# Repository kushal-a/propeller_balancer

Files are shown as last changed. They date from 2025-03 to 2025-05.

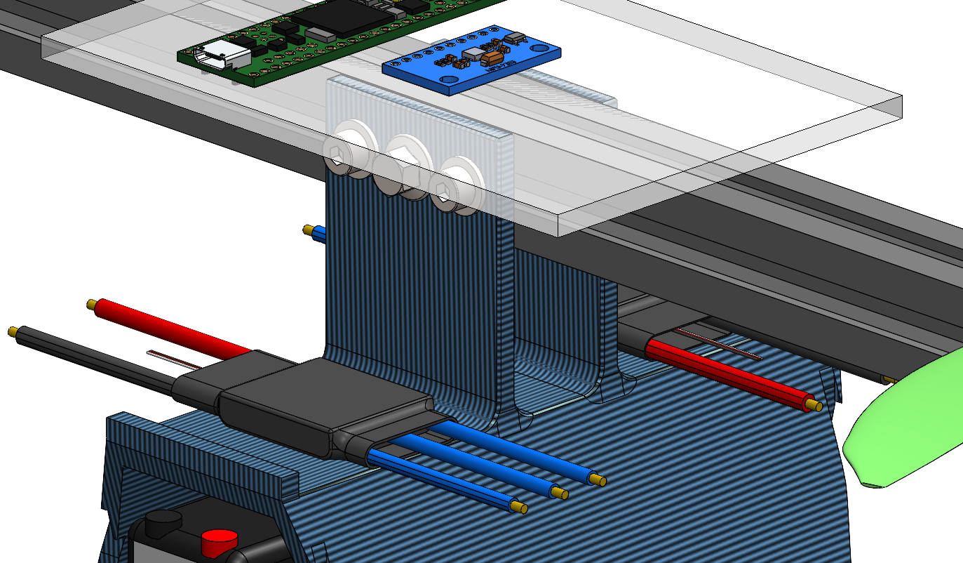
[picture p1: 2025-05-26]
hardware/cad/ESC.png

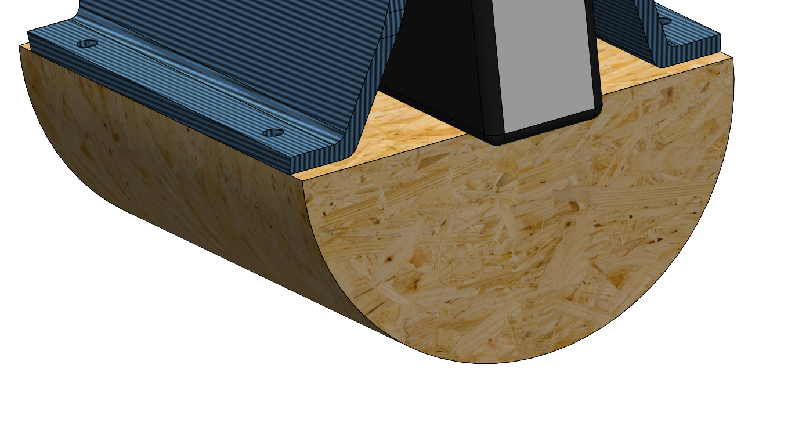
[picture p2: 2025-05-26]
hardware/cad/contact.png

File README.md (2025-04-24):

# propeller_balancer
This repository contains the software required to supervise the `propeller_balancer` developed as a part of my Bachelor's Thesis at Indian Institute of Technology Bombay under the guidance of Prof. Vivek Sangwan. 

# How to use the hardware
The mechanical parts of the project include a semi-circular cylinder on the bottom along with a3D printed part to house the electronics. A 2020T Aluminum profile supports the motors and the end-stops. The acrylic on top of the profile provides space for electronics which are to remain accessible for testing, development and learning.

## Components used
1. Teensy 4.1 microcontroller
2. MPU 6050 IMU sensor for acceleration and gyrometry data
3. 30A BLDC ESC (x2)
4. CC3D BEC (Battery Eliminator Circuit) /Z Power Distribution Board

## Connections
A 10 row port is installed in the hood of the bot. The schematic is shown below.

Internally, the `5V` and `GND` for MUC and IMU are shorted and connected to the Power Distribution board. The `SDA`, `SCL` wires are shorted with jumpers to connect the MUC to the IMU. The `PWMx` pins are connected to the ESC. The `GND` of the ESC's are also connected to the common ground. 

Connect a 10-wire F-F jumper ribbon to the port. First 2 wire connect to `pin1` and `pin2` of the MUC. Next 4 connect to `pins17-14` without twisting. The final 4 connect to the IMU. TODO: Order.

# How to use the package (software)

## Getting started with Teensy

1. Install Arduino IDE
2. Copy and paste the following link in `Arduino IDE`>`File`>`Preferences`>`Additional board manager URLs`
``` html
https://www.pjrc.com/teensy/package_teensy_index.json
```
3. In Arduino IDE go to `Tools`>`Board`>`Board Manager`. Search for Teensy and install the board.
4. Try out your setup with the blink example.
5. Press the button on the Teensy after uploading for it to go into Program mode to receive the compiled code. Once you see Reboot OK, the upload is done.

Ref: https://www.pjrc.com/teensy/tutorial.html

## Setting up IMU
IMU used: MPU 6050 standard IMU sensor

### Power and Communication
Power the IMU with 5V (and GND) from the microcontroller or the power distribution board. For best results, use 5V supply from the power distribution board. 

MPU 6050 uses I2C communication (SDA and SCL) lines. The I2C address of the sensor is 0x68. Connect the SDA and SCL lines of the microcontroller with that of the IMU.

### Software
To communicate with the MPU, we will I2C communication, known as wire communcation in arduino software. Hence, the standard `Wire.h` library will be used. `src/imu` directory has source code for IMU functionality. Import `src/imu/imu.h` for access to IMU functionality. The library provides access to `Theta`, `RateTheta`, `AccX`, `AccY` and `AccZ`. Here, $\theta$ is the nominal angle required for the project. $\theta$ is 0 when the bot balances perfectly.

### Callibration
TODO

## Setting us ESC

### Power and communication
ESC required a 12V input. Connect the two input wires of the ESC with the power supply. ESC provides 3 phase output for motor control; connect the 3 output wires to the motor. It also provides a 5V output (and GND) and takes in a throttle input via jumpers. Ensure to connect the ground of the ESC(s) (and IMU) and microcontroller. The 5V supply of the ESC is unrellibale and hence not used. Throttle is provided as a PWM signal. Speed is proportional to the width of the PWM pulse.

### Software
A BLDC motor with a ESC taking PWM input essentially acts like a servo motor and hence the standard `Servo.h` library is used for producing the PWM. `src/motor` directory has source code for running the motor. Import `src/motor/motor.h` for access to motor functionality. The library provides access to functions to directly produce required PWM signal.

50Hz PWM has is a 20ms period. 
| Duration of high signal per period | Effect in Servo | Effect in BLDC |
| :-----| :----: | :----: |
|1ms|0 degrees|min RPM|
|2ms| 180 degrees|max RPM|

### Callibration 
Every ESC has to caallibrated. The input PWM frequency can vary from 50-60Hz and min max pulse width can vary about 1ms and 2ms respectively. 

For some reason the callibration of both motors simulataneously by code 

## Using the Power Distribution Board
The power distribution board needs a 12V supply. Adjacent to the spots for 12V supply to the ESC. These lines are shorted. On the other end, the 5V terminals will be used to power the microcontroller. The power distribution board has a battery eliminator circuit (BEC) to eliminated the need of a seperate battery for the microcontroller.

# Resources
[1] Teensy KiCAD footprint @ https://github.com/XenGi/teensy.pretty

[2] Teensy KiCAD symbol @ https://github.com/XenGi/teensy_library
# Credits
[1] __Muskan Patel__ and __Kyari Ponkiya__ for initial work on the project.

[2] __Mechatronics Lab__, IIT Bombay for workspace and technological support. __Mr. Tejas__ and __Mr. Vijay__ from Mechatronics Lab.

[3] Members of __INDUS Lab__, IIT Bombay for their support.

[4] __Microfactory__, IIT Bombay with machinary support.

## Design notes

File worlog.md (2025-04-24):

# 24/04
Increased hole size of propeller from 5mm dia to 6mm dia for almost a bit more than half the length from the bottom. This was used for mounting. Cut holes in the center of the motor mounts to give space for the recess part of the shaft coming out of the motor. Assembled the new propellers, base with countersunk holes, motor mounts and endstops

# 23/04

Made countersunk holes in the base and laser cut the supports at Microfactory

# 22/04 

Debugged code for compillation. Received propeller.

# 19/04

Checked for proper propeller size required. Sourced from Amazon. Propeller bought - 6045 

# 17/04

Met with professor for changing the propeller size. Shifting focus to rudimentary implementation at priority

# 15/04

## Testing of motor to get motor constant

### Test 1
#### Aim 
Checking variability of speed of motor (without propeller)
#### Setup
1. Test conducted without propeller. 
2. Code run: motor.ino. 
3. Speed given as % input from Serial monitor.
#### Observations
1. As motor speed input was increasing the motor speed was monotonically increasing. The speed was judged by manually hearing the sound made by the motor. Higher frequency implying faster rotation.
2. Motor only started rotating when motor speed was >=10%

### Test 2

Checking variability of thrust by varying speed of motor-propeller setup
#### Setup
1. Test conducted with propeller. 
2. Code run: motor.ino. 
3. Speed given as % input from Serial monitor.
4. The motor was mounted to a wooden plank and the wooden plank was taped to an iron block of mass ~2.8Kgs. The entire setup is placed on a weighing scale and set to 0 when the motor is not rotating.
#### Observations
1. As motor speed input was increasing the motor-propeller sped up until 40% after which it was abmigious. The speed was judged by manually hearing the sound made by the motor. Higher frequency implying faster rotation.
    1. After this observation, the ESC was recallibrated and test was run again. Same observations were noted.
    2. The propeller was then removed and test 1 was run again. The earlier made observations of test 1 stood again.
2. Motor only started rotating when motor speed was >=10%.
3. Raw data collected from the test is available in `data`>`thrust_test`.

#### Conclusion
1. There is some interference in the motor speed phenomenon on adding the propeller.
2. Current reading should be noted to eliminate current limitng effects.

### Test 3

Checking variability of thrust and current by varying speed of motor-propeller setup
#### Setup
1. Test conducted with propeller. 
2. Code run: motor.ino. 
3. Speed given as % input from Serial monitor.
4. The motor was mounted to a wooden plank and the wooden plank was taped to an iron block of mass ~2.8Kgs. The entire setup is placed on a weighing scale and set to 0 when the motor is not rotating.
#### Observations
1. As motor speed input was increasing the motor-propeller sped up until 40% after which it was abmigious. The speed was judged by manually hearing the sound made by the motor. Higher frequency implying faster rotation.
2. Current reached 1.88A at 40% speed and saturated there after that. The power supply used had a limiting current of 2A.
3. Raw data collected from the test is available in `data`>`thrust_test`.

#### Conclusion
1. Current saturation was causing a drop in observed speed.
2. Higher amperage power supply is to be used.
3. Quadratic treadline fit for 0-40% speed was 

    $$\textit{Thrust (in g)} = 0.036*\textit{Speed}_{\%}^2 + 1.5723*\textit{Speed}_{\%}+0.6373$$ 

    The quadratic and linear part have significant contribution to the calculated value. The constant contributed to <10\% of the calculated value.

### repeating Test 3 with higher amperage power supply

Acrylic broke and the motor flew in air. Luckily the wire came loose and the motor stopped.

DO NOT USE MOTOR WITH speed > 30% !!!!!

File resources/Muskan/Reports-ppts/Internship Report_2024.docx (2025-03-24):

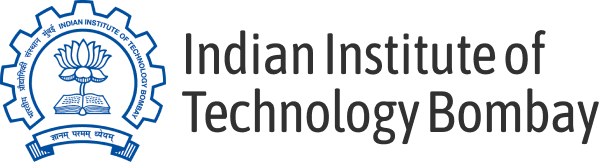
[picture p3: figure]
100+ Top Indian Institute of Technology Bombay Online Courses [2024] | Class Central
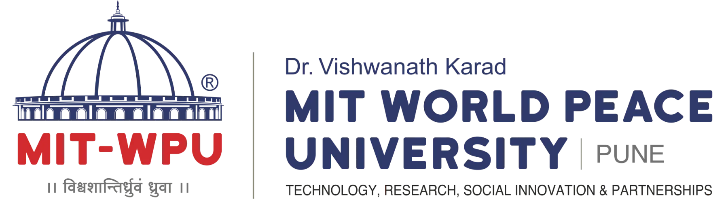
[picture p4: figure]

DESIGN AND CONTROL OF TORSO BALANCING MECHANISM FOR BIPEDAL WALKING ROBOT

An Internship Report Submitted to

DR. VISHWANATH KARAD

MIT WORLD PEACE UNIVERSITY

Submitted by,

Muskan Hiteshkumar Patel (1032200264)

Under the supervision of

Prof. Vivek Sangwan

and

Ass. Prof. Dr. Ashish H. Pawar

School of Mechanical Engineering

MIT World Peace University, Pune

Kothrud, Pune-411038

(Period from 15th January, 2024 to 14th May, 2024)

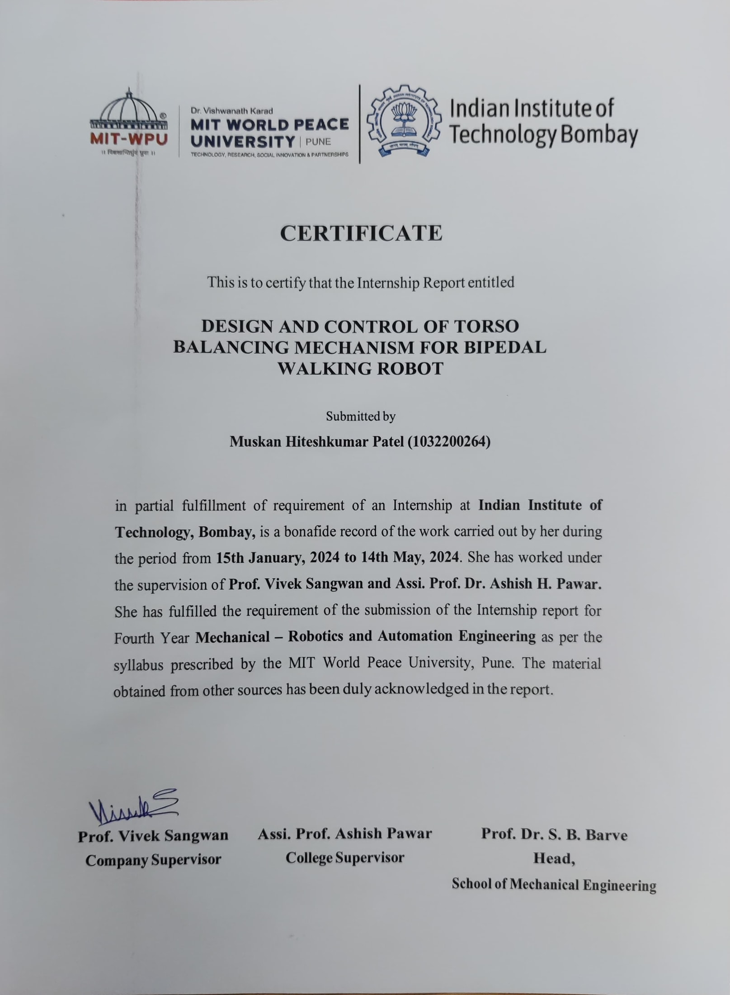
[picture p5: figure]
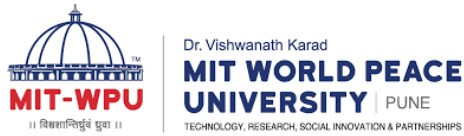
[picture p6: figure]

Vision and Mission

Vision of Faculty of Engineering and Technology

To be a globally recognized leader in Engineering Education having a constructive impact on society.

Mission of Faculty of Engineering and Technology

1. To achieve academic excellence through Continuously Updated Education (CUEd).
2. To create environment of technology research and social innovation by establishing trans-disciplinary centers of excellence.
3. To establish strong partnerships with reputed industry and research organizations.
4. To promote ethical and universal value based professional education.

Vision of School of Mechanical Engineering

To be a center of academic excellence in Mechanical Engineering for sustainable development.

Mission of School of Mechanical Engineering

1. To impart comprehensive knowledge in mechanical engineering and foster skills to enhance economic development of the nation.
2. To facilitate trans-disciplinary research leading to innovative technologies.
3. To collaborate with academia, industry and research organization globally.
4. To nurture students for lifelong learning and ethical professional career.

ACKNOWLEDGEMENT

It gives me great pleasure to work as a research intern on project named “DESIGN AND CONTROL OF TORSO BALANCING MECHANISM FOR BIPEDAL WALKING ROBOT” at IIT Bombay. In presenting this internship project work, a number of hands helped me directly and indirectly. Therefore, it becomes my duty to express my gratitude towards them.

I am grateful to Prof. Dr. Vivek Sangwan for giving me the opportunity to work as an intern at IIT Bombay and giving proper guidance throughout the internship duration. His timely suggestions made it possible to complete this internship for me. All efforts might have gone in vain without his valuable guidance. I would like to express my heart-felt gratitude towards Prof. Dr. Ganesh Kakandikar, in School of Mechanical Engineering, to recommend me for this project under the guidance of Prof. Dr. Vivek Sangwan. I would also like to thank Asst. Prof. Dr. Ashish Pawar for supervising and counselling me on regular basis during the internship.

I will fail in my duty if I won't acknowledge a great sense of gratitude to the head of School of Mechanical Engineering, Prof. Dr. Shivprakash B. Barve and the entire staff members in the School of Mechanical Engineering for their cooperation.

Muskan Hiteshkumar Patel

BTech Mechanical Engg.

PRN No: 1032200264

ABSTRACT

Bipedal walking robots represent a significant advancement in robotics, mimicking human-like locomotion and balancing capabilities. In this study, we focus on the design and control of a torso balancing mechanism for such robots. The proposed mechanism employs a plank structure with two BLDC (Brushless Direct Current) motors mounted on either side, tasked with dynamically stabilizing the robot during locomotion. This research aims to derive the dynamical equations governing the motion of the plank, implement a PID (Proportional-Integral-Derivative) controller to regulate the motor speeds, and integrate feedback from an MPU6050 inertial measurement unit for real-time stability control. The dynamics of the plank are derived using principles of classical mechanics and control theory. The equations of motion consider the inertial properties of the plank, the torques generated by the BLDC motors, and the external disturbances encountered during operation. By modeling the system dynamics, we establish a mathematical framework that governs the interaction between the plank's motion and the control inputs provided by the motors. To achieve stable bipedal locomotion, a PID controller is implemented to regulate the motor speeds in response to deviations from the desired orientation. The PID controller utilizes feedback from the MPU6050 IMU, which provides accurate measurements of the plank's orientation and angular velocities. By continuously adjusting the motor speeds based on the error between the desired and measured orientations, the PID controller effectively counteracts disturbances and maintains the robot's balance. The design of the torso balancing mechanism involves careful consideration of mechanical, electrical, and control aspects. The selection of BLDC motors with appropriate torque and speed characteristics is crucial for achieving the desired balancing performance. Additionally, the mechanical design of the plank must ensure structural integrity while minimizing weight and inertia to facilitate agile locomotion. Experimental validation of the proposed mechanism is conducted using a prototype bipedal walking robot platform. Real-world testing scenarios are employed to assess the system's performance under various conditions, including uneven terrain and external perturbations. The effectiveness of the PID controller in stabilizing the robot's torso is evaluated through quantitative metrics such as orientation error and stability margins. The outcomes of this research contribute to the advancement of bipedal walking robotics by providing a robust solution for torso balancing mechanisms. The derived dynamical equations, coupled with the PID control approach, offer insights into the complex interactions between mechanical design and control algorithms in achieving stable locomotion. The experimental results demonstrate the feasibility and effectiveness of the proposed mechanism in real-world scenarios, paving the way for further developments in bipedal robot locomotion and human-robot interaction.

CONTENTS

Sr. No. | | Name of Sections | Page No.
| | Certificate
| | Vision and Mission
| | Acknowledgement
| | Abstract
1. | | DETAILS OF THE ORGANIZATION
2. | | INTRODUCTION
| 1.1 | Background
| 1.2 | Problem Statement
| 1.3 | Objectives
| 1.4 | Scope
3. | | REVIEW OF LITERATURE
4. | | METHODOLOGY
5. | | RESULTS/ANALYSIS
6. | | CONCLUSION
7. | | FUTURE SCOPE
| | APPENDIX A (Acronyms and Abbreviations)
| | APPENDIX B (Glossary)
| | Bibliography

#### 1. DETAILS OF THE ORGANIZATION

Established in 1958, the Indian Institute of Technology Bombay (IIT Bombay) is one of the premier engineering institutes in India. Located in Powai, Mumbai, it is renowned for its excellence in education, research, and innovation. Offering undergraduate, postgraduate, and doctoral programs across various disciplines of engineering, science, design, and management, IIT Bombay consistently ranks among the top engineering institutes globally. It boasts state-of-the-art facilities, cutting-edge research centers, and a vibrant campus life. With a strong emphasis on interdisciplinary collaboration and industry partnerships, IIT Bombay fosters a conducive environment for students and faculty to pursue academic excellence and contribute to societal development. Its alumni network spans the globe, with graduates making significant contributions to academia, industry, and entrepreneurship. IIT Bombay continues to uphold its legacy of producing leaders and innovators who drive technological advancements and social change.

Mechanical Engineering at the Indian Institute of Technology Bombay (IIT Bombay) is a flagship program known for its academic excellence, research opportunities, and industry connections. The department offers undergraduate, postgraduate, and doctoral programs in Mechanical Engineering, covering a wide range of subjects such as thermodynamics, fluid mechanics, manufacturing processes, robotics, and automotive engineering. With world-class faculty members, state-of-the-art laboratories, and cutting-edge research facilities, students receive comprehensive training in theoretical concepts and practical skills. The curriculum emphasizes hands-on learning through projects, internships, and industry collaborations, preparing graduates for successful careers in diverse sectors including aerospace, automotive, energy, manufacturing, and robotics. Alumni of the Mechanical Engineering program at IIT Bombay are renowned for their contributions to academia, industry, and research, making significant advancements in technology and addressing complex engineering challenges on a global scale.

#### 2. INTRODUCTION

#### 1.1 Background

Bipedal walking robots have long been a subject of fascination and research in the field of robotics, primarily due to their resemblance to human locomotion and the challenges they pose in terms of control and stability. Inspired by nature, these robots aim to replicate the complex motion and balance exhibited by humans while walking. Achieving stable bipedal locomotion requires not only advanced mechanical design but also sophisticated control algorithms to maintain balance and stability in dynamic environments. The concept of torso balancing mechanisms for bipedal robots stems from the fundamental principle of maintaining the center of mass within the support polygon to prevent toppling over. Traditionally, bipedal robots have employed various strategies for balance, including passive dynamic walking, active joint control, and external support systems. However, the development of torso balancing mechanisms presents a promising approach to enhance the stability and agility of bipedal robots, particularly in scenarios involving uneven terrain or external disturbances.

#### 1.2 Problem Statement

Despite significant advancements in robotics, achieving stable bipedal locomotion remains a challenging problem due to the inherent complexity of dynamic balance control. One of the key challenges lies in designing effective torso balancing mechanisms that can dynamically adjust the robot's posture in real-time to counteract disturbances and maintain stability during locomotion. The integration of such mechanisms requires a comprehensive understanding of the mechanical, electrical, and control aspects involved, as well as the development of robust algorithms for feedback control. The specific problem addressed in this study revolves around the design and control of a torso balancing mechanism for a bipedal walking robot. The mechanism consists of a plank structure with BLDC motors mounted on either side, tasked with generating variable torques to stabilize the robot's torso. The challenge lies in deriving the dynamical equations governing the motion of the plank, designing an effective PID controller to regulate the motor speeds based on feedback from an IMU, and validating the performance of the mechanism through real-world experiments.

#### 1.3 Objectives

The primary objective of this research is to design and implement a torso balancing mechanism for a bipedal walking robot capable of maintaining stability during locomotion. To achieve this overarching goal, the following specific objectives are outlined:

- Derive the dynamical equations governing the motion of the plank structure with mounted BLDC motors.
- Design and implement a PID controller to regulate the motor speeds based on feedback from an MPU6050 IMU.
- Integrate the torso balancing mechanism into a prototype bipedal walking robot platform.
- Conduct experimental validation to assess the performance and effectiveness of the mechanism under various operating conditions.

By addressing these objectives, we aim to contribute to the advancement of bipedal walking robotics by providing a robust solution for torso balancing mechanisms that can enhance stability and agility in dynamic environments.

#### 1.4 Scope

This study focuses specifically on the design and control of a torso balancing mechanism for a bipedal walking robot, with emphasis on the mechanical design, dynamical modeling, control algorithm development, and experimental validation. The scope encompasses the following key aspects:

- Mechanical Design: The design of the plank structure and mounting system for the BLDC motors, considering factors such as weight, inertia, and structural integrity.
- Dynamical Modeling: Derivation of the equations of motion for the plank structure, taking into account the inertial properties of the system and the torques generated by the motors.
- Control Algorithm Development: Implementation of a PID controller to regulate the motor speeds based on feedback from an MPU6050 IMU, with the objective of maintaining balance and stability.
- Experimental Validation: Real-world testing of the torso balancing mechanism using a prototype bipedal walking robot platform, including assessment of stability, performance, and robustness under various conditions.

While this study focuses on a specific torso balancing mechanism design, the concepts and methodologies developed can be generalized to other bipedal robot platforms and applications. The scope also includes potential extensions and future research directions, such as advanced control strategies, sensor fusion techniques, and integration with higher-level motion planning algorithms.

In summary, this research aims to address the challenges associated with torso balancing in bipedal walking robots through a comprehensive approach encompassing mechanical design, dynamical modeling, control algorithm development, and experimental validation. By achieving the outlined objectives within the defined scope, we aim to contribute to the advancement of bipedal robotics and pave the way for more agile and stable robotic locomotion in the future.

#### 3. REVIEW OF LITERATURE

The research paper by Mohanarajah Gajamohan, ‘The Cubli: A Cube that can Jump Up and Balance’, introduces the Cubli, a 15x15x15 cm cube capable of jumping up and balancing on a corner. Momentum wheels on three faces rotate at high speeds and then brake suddenly to make the Cubli jump. Controlled motor torques are applied to balance it on the corner. The paper tracks the development of the one-dimensional prototype at ETH Zurich and presents initial results. Inverted pendulum systems have a rich history and are used to test new control concepts. The Cubli offers unique features like a small footprint and the ability to jump without external support.

The one-dimensional prototype consists of a plastic plate holding a momentum exchange wheel through a motor at its center. The plate pivots around a corner on a horizontal plane. The dynamics of the setup involve tilt angles and rotational displacements, with non-linear equations governing the system. The paper aims to present the concept of the three-dimensional Cubli and its development, including design, modeling, identification, and control. A control procedure is detailed to eliminate sensor offsets during balance maneuvers.

Jumping up trials were conducted with additional steel plates to match the mass and inertia properties of the full Cubli. The electronics setup includes an evaluation board with a Cortex-M3 controller, IMUs, and a motor controller. The CANopen protocol facilitates communication between the motor controller and the evaluation board. An RC servo-driven braking mechanism is used, and a rotary magnetic encoder measures angles for debugging. The software framework employs the STM32 port of the FreeRTOS scheduler and an open-source development environment named ODeV.

The Cubli's jumping strategy involves stopping a momentum wheel to make it jump about its edge. The small footprint and independent jumping capability make the Cubli an interesting test-bed for control engineers and a captivating demonstration for the public. The paper discusses the development of new control algorithms for the Cubli system and highlights its unique features compared to other 3D inverted pendulum test-beds. The LQR feedback controller is designed for stabilization, and the system is capable of recovering from angles up to 7 degrees.

In conclusion, the Cubli project represents an innovative approach to inverted pendulum systems, showcasing advanced control concepts and demonstrating unique capabilities in jumping and balancing. The development of the one-dimensional prototype serves as a stepping stone towards the realization of the three-dimensional Cubli. The paper provides insights into the design, dynamics, electronics, and software aspects of the Cubli project, emphasizing its potential for further research and development in the field of control systems and robotics.

Ashish Vishwakarma discusses the design and implementation of a PID controller for a non-linear balancing beam system using Arduino. The system involves a nonlinear unstable 2-degree of freedom beam with BLDC motors, widely used in control engineering. The goal is to enable the beam to move freely around a pivot point without losing momentum, achieved by designing a dedicated PID controller. The system utilizes an Arduino kit to develop the PID controller code, controlling two brushless motors to calibrate the beam using BLDC motors with flaps and an MPU6050 or MPU9250 IMU module to calculate the angle. The controlled parameter is the inclination angle of the beam, with the error being the difference between the actual and desired angles.

The PID controller algorithm involves calculating the error, integral, derivative, and output values in a loop. The error is the difference between the setpoint and measured value, the integral is the accumulation of errors over time, and the derivative is the rate of change of the error. The output is calculated using proportional, integral, and derivative constants multiplied by their respective error terms. The PID values are constrained within a range to ensure they fall within the acceptable PWM signal limits of 1000us to 2000us.

The document also references various sources related to PID control, including books by Karl Johan Åström and Tore Hägglund, as well as external links for further information on PID controllers. It highlights the importance of tuning the PID controller parameters for optimal performance in controlling the beam system. The PID controller's fast response, when properly tuned, is crucial for achieving the desired balance and stability of the beam system.

Overall, the document provides a detailed insight into the design, control, and implementation of a PID controller for a nonlinear beam model using Arduino. It emphasizes the significance of PID control in achieving stability and balance in complex systems like the balancing beam. The integration of sensors, motors, and the PID algorithm showcases a practical application of control engineering principles in real-world scenarios.

#### 4. METHODOLOGY

1) Dynamical Modeling:

The initial phase of the methodology involves deriving the dynamical equations governing the motion of the plank structure. This step is crucial for understanding the underlying physics of the system and designing effective control algorithms for maintaining balance during locomotion. The dynamical modeling process begins by defining the relevant variables and parameters involved in the motion of the plank and the BLDC motors. These may include the mass and inertia of the plank, the torque constants and friction coefficients of the motors, and the external forces acting on the system. Using principles of classical mechanics, such as Newton's laws of motion and Euler's equations of motion for rigid bodies, the equations of motion for the system are derived. This typically involves considering the torques generated by the motors, the inertial forces and moments of the plank, and any external disturbances or perturbations affecting the system. MATLAB may be used for symbolic manipulation and numerical simulations to validate the derived equations and understand the system dynamics. Simulation results provide insights into the behavior of the system under different operating conditions and inform the design of the control algorithm.

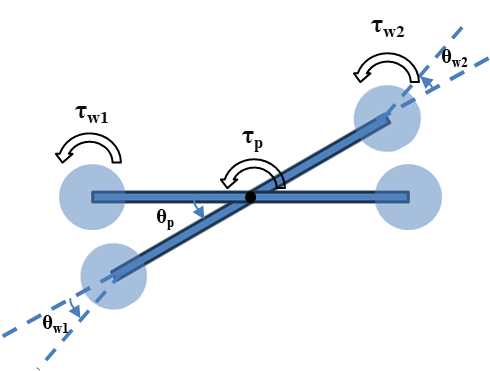
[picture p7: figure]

Fig. 1 Labelled Diagram of the system to be balanced

Considering the above condition where the plank is deflected by theta p angle in anticlockwise direction, assuming that the inertia wheels rotate in anticlockwise direction to balance the plank. The dynamical equations are derived using two different methods to verify the equations – Newtonian method and Lagrangian Method. The equations obtained are as follows:

τw1 = Iw * ӫw1

τw2 = Iw * ӫw2

τp = (2*mw*lw²+ Ip)* ӫp

The above torque τp should be equal to the sum of the torques of the inertia wheels τw1 and τw2 because there is no external torque acting on the plank.

To verify the equations, these are tested in MATLAB using ODE45 differential equation solver. The energy check is done to verify the equations.

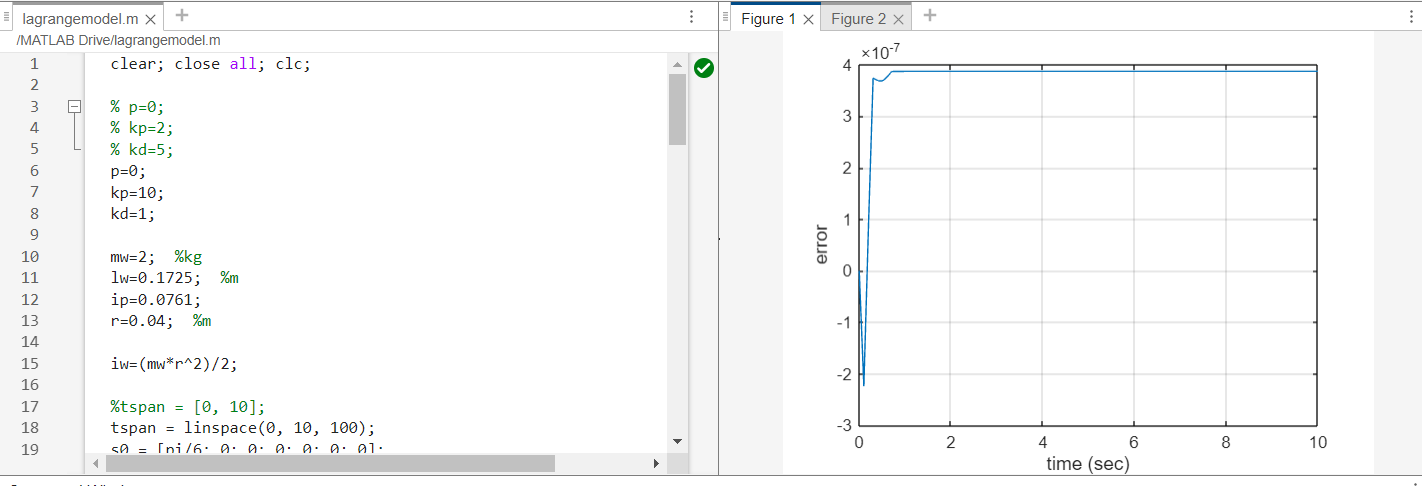
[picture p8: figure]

Fig. 2 Energy Check in MATLAB, Error = 10⁻⁷

2) Mechanical Design:

After deriving the dynamical equations, the next phase of the methodology involves the mechanical design of the torso balancing mechanism for the bipedal walking robot. This process begins with conceptualizing the overall structure and layout of the mechanism, taking into account factors such as weight distribution, structural integrity, and compatibility with the robot's existing framework. CAD software such as SolidWorks or Fusion 360 is utilized to create detailed 3D models of the mechanism, allowing for visualization and simulation of its components and functionality. During the mechanical design phase, considerations are made regarding the selection of materials, dimensions, and mounting points for the components. The plank structure, which serves as the primary support for the BLDC motors, is designed to withstand the dynamic loads and forces encountered during locomotion. Attention is also given to the placement and orientation of the motors to ensure optimal torque distribution and balance. Iterative design cycles may be employed to refine the initial concepts and address any potential issues or limitations identified during the design process. Feedback from simulation results, as well as input from domain experts, is used to iteratively improve the mechanical design until a final design iteration is reached that meets the requirements for stability, performance, and manufacturability.

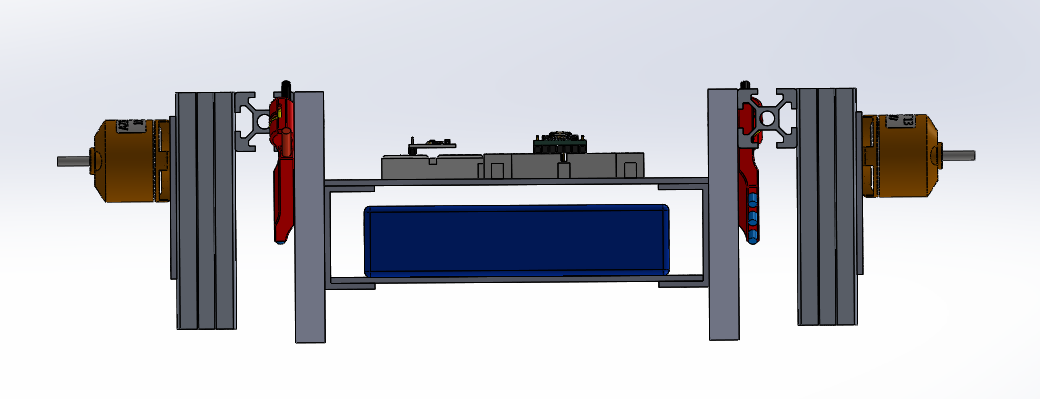
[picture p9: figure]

Fig. 3 Front View of the Design

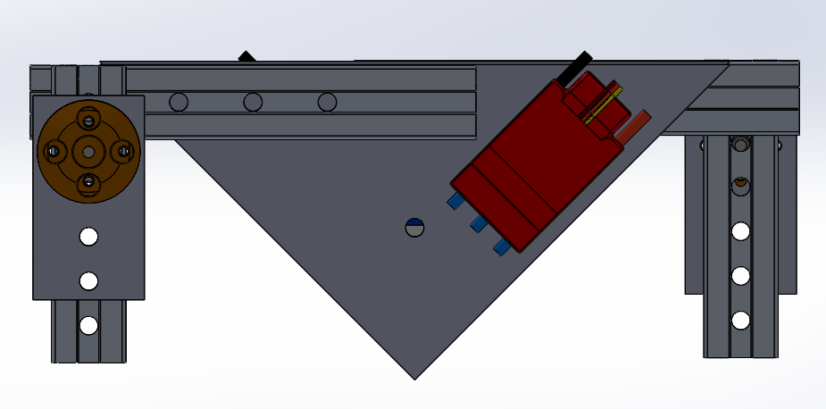
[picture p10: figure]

Fig. 4 Side View of the Design

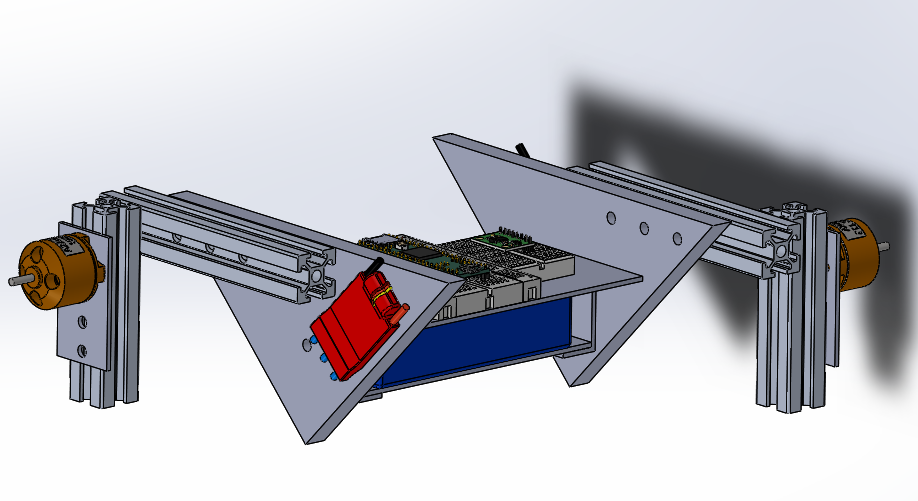
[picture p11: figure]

Fig. 5 Isometric View of the Design

3) Component Selection:

Once the mechanical design is finalized, the next step is to select appropriate components for the torso balancing mechanism. This includes choosing BLDC motors with suitable torque and speed characteristics to provide the necessary actuation for balancing the robot's torso. Considerations are made regarding factors such as power consumption, voltage requirements, and compatibility with the control system. Additionally, motor controllers, power supplies, and mounting hardware are selected based on compatibility with the chosen motors and the overall robot platform. Components are evaluated based on their performance specifications, reliability, and cost-effectiveness to ensure they meet the requirements of the project within the allocated budget and timeline.

The list of selected components is given below along with their specifications:

i. A2212 1000KV BLDC Motor:
- KV Rating: 1000
- Motor Type: Brushless DC (BLDC)
- Voltage: 7.4V - 11.1V (3S to 4S LiPo battery compatible)
- Maximum Current: 12A
- Maximum Power: 140W
- Dimensions: 27.5mm x 27.5mm x 27mm
- Shaft Diameter: 3.17mm
- Weight: Approximately 47g
- Ideal for small to medium-sized drones, RC aircraft, and robotic applications.

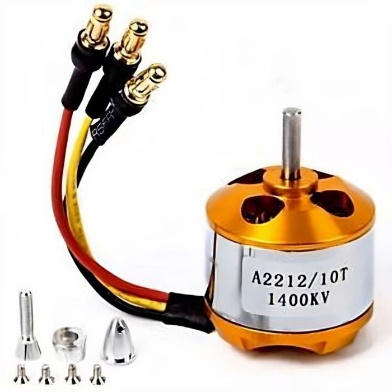
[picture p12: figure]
A2212 1400KV BLDC Brushless Motor

Fig. 6 A2212 BLDC Motor

ii. SimonK 30A ESC (Electronic Speed Controller):
- Continuous Current: 30A
- Burst Current: 40A
- Voltage: 2S - 4S LiPo (7.4V - 14.8V)
- BEC (Battery Elimination Circuit): None (External BEC or UBEC may be required for powering the control circuitry and servos)
- Compatible with most BLDC motors, optimized for high-performance and rapid throttle response.
- Supports various throttle calibration methods and features programmable options for motor timing and braking.

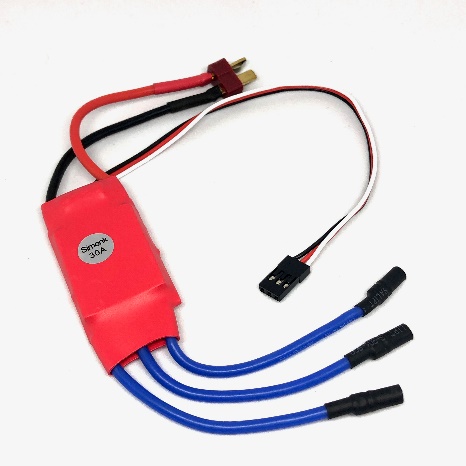
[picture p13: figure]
SimonK 30A 2-3S Brushless ESC For RC Model (High Quality)

Fig. 7 Simonk ESC

iii. LiPo Battery 3S 2200mAh:
- Cell Count: 3S (3 Cells in Series)
- Voltage: 11.1V (Fully Charged)
- Capacity: 2200mAh (Milliampere-hours)
- Discharge Rate: Typically rated at 25C (Continuous discharge current = 25C x Capacity)
- Connector Type: Typically comes with a XT60 or T-Connector for power connection.
- Suitable for providing power to the BLDC motor and ESC, commonly used in RC vehicles, drones, and robotics due to its high energy density and lightweight design.

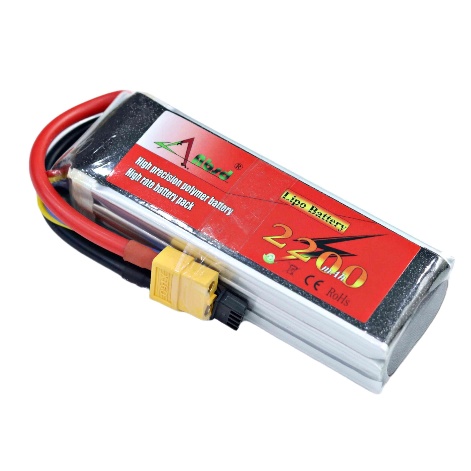
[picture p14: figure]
11.1V 2200mAh 3S 25C Lipo Battery With XT60 Plug (Brand ABSD)

Fig. 8 LiPo 3S Battery

iv. MPU6050 (Inertial Measurement Unit):
- Gyroscope Range: ±250, ±500, ±1000, or ±2000 degrees per second (dps)
- Accelerometer Range: ±2g, ±4g, ±8g, or ±16g
- Operating Voltage: 3.3V - 5V
- Communication: I2C (Inter-Integrated Circuit) interface
- Integrated 3-axis MEMS (Micro-Electro-Mechanical Systems) gyroscope and accelerometer
- Provides accurate measurements of angular velocity and linear acceleration in three axes.
- Ideal for motion sensing and orientation tracking applications in robotics, drones, and motion-controlled devices.

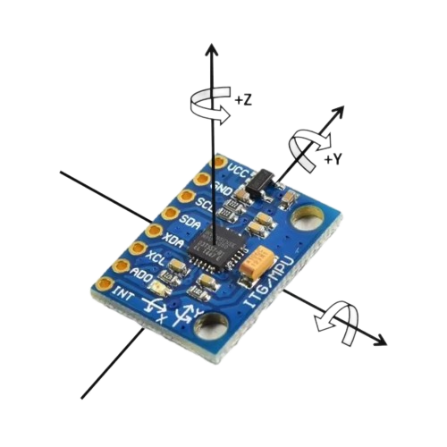
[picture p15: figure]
GitHub - ElectronicCats/mpu6050: MPU6050 Arduino Library

Fig. 9 MPU6050 (IMU)

4) Controller Design:

Building upon the dynamical model developed in the previous step, the next phase of the methodology involves designing a control algorithm to regulate the motor speeds and maintain balance in real-time. A PID controller is commonly used for this purpose due to its simplicity and effectiveness in controlling linear and nonlinear systems. The PID controller takes feedback from an IMU, such as the MPU6050, which provides measurements of the robot's orientation and angular velocities. The control algorithm calculates the error between the desired and measured orientations and adjusts the motor speeds accordingly to minimize this error and stabilize the robot's torso. The design of the PID controller involves tuning the proportional, integral, and derivative gains to achieve desired stability, response time, and robustness to disturbances. Manual tuning methods, such as trial and error or Ziegler-Nichol’s method, may be used initially to obtain rough estimates of the PID gains. Subsequently, more advanced tuning techniques such as auto-tuning algorithms or optimization algorithms like particle swarm optimization (PSO) or genetic algorithms may be employed to fine-tune the controller parameters for optimal performance. The graph shown below shows the MATLAB simulation of balancing of the torso using PID controller.

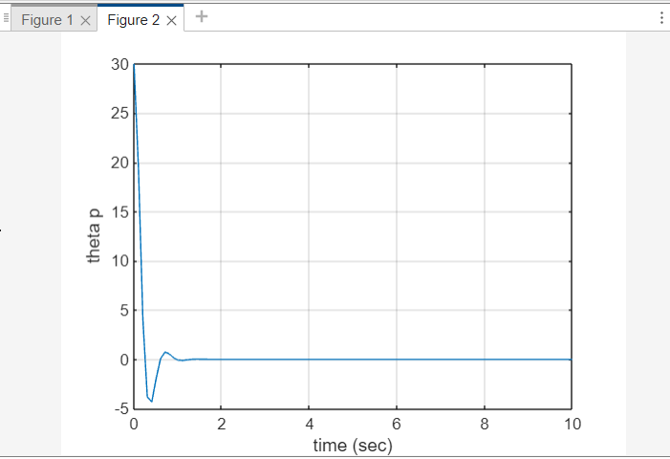
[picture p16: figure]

Fig. 10 The output after applying PID controller – theta p eventually settles at zero which is the setpoint given to balance the system.

5) PID Tuning and Optimization:

Once the PID controller is designed, it needs to be tuned to ensure optimal performance of the system. This involves adjusting the proportional, integral, and derivative gains of the controller to achieve desired stability, response time, and robustness to disturbances. Manual tuning methods, such as trial and error or Ziegler-Nichols method, may be used initially to obtain rough estimates of the PID gains. Subsequently, more advanced tuning techniques such as auto-tuning algorithms or optimization algorithms like particle swarm optimization (PSO) or genetic algorithms may be employed to fine-tune the controller parameters for optimal performance.

6) Implementation and Integration:

With the mechanical design, component selection, dynamical modeling, and controller design completed, the next step is to implement the torso balancing mechanism and integrate it into the bipedal walking robot platform. This involves assembling the mechanical components, wiring the electrical connections, and programming the control algorithm on a microcontroller or embedded system. Careful attention is paid to ensure proper calibration and synchronization of the motors, sensors, and control system to facilitate seamless operation. Compatibility with the existing robot platform and communication protocols is also considered to ensure smooth integration and interoperability with other subsystems.

7) Experimental Validation:

Once the torso balancing mechanism is implemented and integrated, experimental validation is conducted to assess its performance under real-world conditions. This involves conducting a series of tests and experiments to evaluate the stability, responsiveness, and robustness of the mechanism. Test scenarios may include walking on various terrains, navigating obstacles, and reacting to external disturbances such as pushes or pulls. Data logging and analysis tools are used to collect and analyze data from sensors and actuators to quantify the performance of the mechanism and identify areas for improvement.

8) Iterative Refinement:

Based on the results of the experimental validation, iterative refinement may be performed to further optimize the design and control parameters of the torso balancing mechanism. This may involve making adjustments to the mechanical design, fine-tuning the PID controller gains, or incorporating additional sensors or feedback mechanisms to enhance the performance and robustness of the system. The iterative refinement process continues until satisfactory performance is achieved, meeting the desired stability and agility requirements for bipedal locomotion.

In summary, the methodology outlined above provides a systematic approach to design and implement a torso balancing mechanism for a bipedal walking robot, integrating mechanical design, dynamical modeling, control algorithm development, and experimental validation. By following this methodology, we aim to develop a robust and effective solution for enhancing the stability and agility of bipedal robots during locomotion.

#### 5. RESULT/ANALYSIS

The results and analysis section presents the outcomes of the experimental validation conducted on the torso balancing mechanism for the bipedal walking robot. This section provides insights into the performance, stability, and robustness of the mechanism under various conditions, along with a detailed analysis of the experimental data.

1) Actual Prototype:

The actual prototype fabricated:

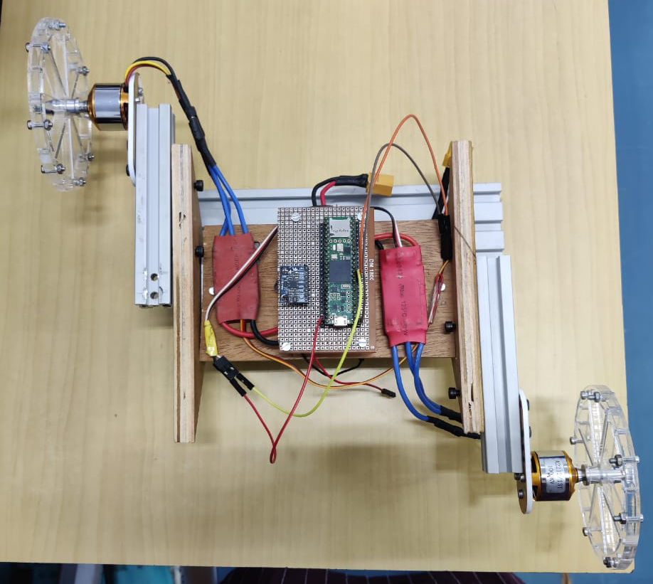
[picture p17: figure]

Fig. 11 Top View of the Prototype

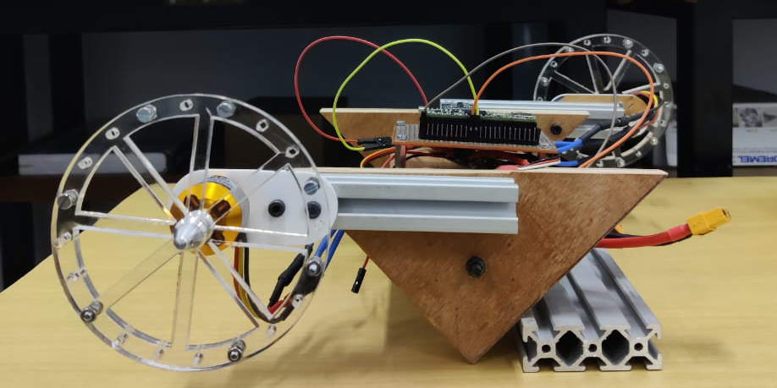
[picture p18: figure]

Fig. 12 Side View of the Prototype

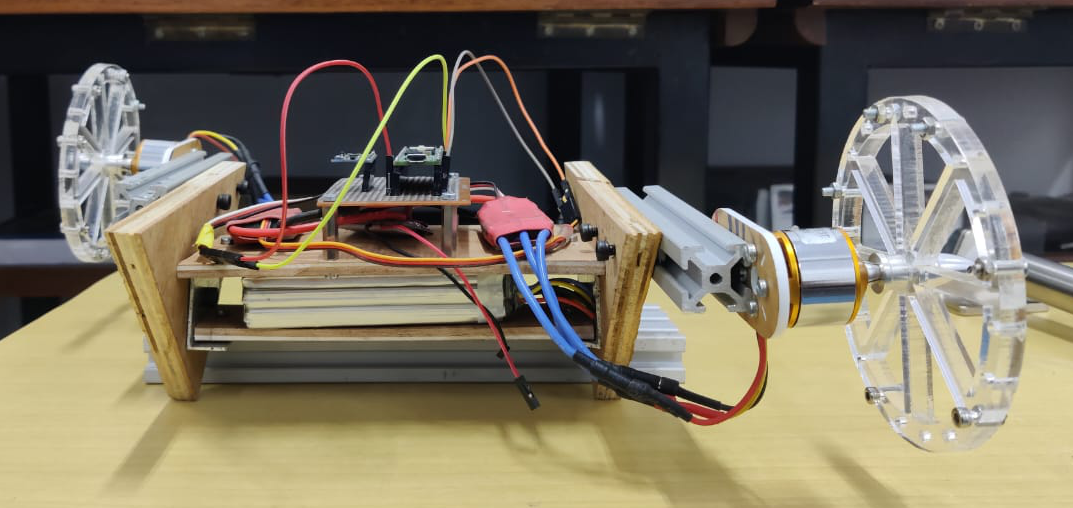
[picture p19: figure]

Fig. 13 Front View of the Prototype

2) Stability and Balance:

The primary objective of the experimental validation was to assess the stability and balance of the bipedal walking robot equipped with the torso balancing mechanism. Through a series of tests, including stationary balancing and dynamic locomotion, the mechanism demonstrated the ability to maintain stability and prevent toppling over. During stationary balancing tests, the robot was able to maintain an upright position without external support, indicating effective torque generation and control by the BLDC motors. The PID controller continuously adjusted motor speeds based on feedback from the MPU6050 IMU, ensuring the robot remained balanced even in the presence of minor disturbances.

3) Response Time and Agility:

Another aspect evaluated during the experimental validation was the response time and agility of the torso balancing mechanism. Tests involving rapid changes in orientation and direction revealed the mechanism's ability to react quickly to external stimuli and adjust motor speeds accordingly. The PID controller exhibited rapid response times, allowing the robot to recover from perturbations and maintain balance during dynamic maneuvers. This agility is crucial for bipedal robots operating in dynamic environments where quick adjustments are necessary to navigate obstacles and uneven terrain.

4) Robustness to Disturbances:

Robustness to external disturbances was also examined during the experimental validation. Tests involving pushes, pulls, and simulated terrain irregularities provided insights into the mechanism's ability to withstand external forces and maintain stability during locomotion. The torso balancing mechanism demonstrated resilience to various disturbances, thanks to the adaptive control provided by the PID controller. In scenarios where the robot encountered unexpected obstacles or uneven terrain, the mechanism adjusted motor speeds to counteract disturbances and prevent loss of balance.

5) Energy Efficiency:

Energy efficiency was another important aspect considered during the experimental validation. By monitoring power consumption and battery usage during different locomotion tasks, insights were gained into the overall efficiency of the mechanism and its impact on the robot's endurance and autonomy. The BLDC motors, ESC, and LiPo battery operated efficiently, providing adequate power to the mechanism while optimizing energy usage. This ensured extended operational periods and enhanced the robot's ability to perform prolonged tasks without requiring frequent recharging or battery replacement.

6) Data Analysis and Visualization:

Experimental data collected during the validation tests were analyzed using statistical methods and visualization techniques to extract meaningful insights into the mechanism's performance. Graphs, charts, and plots were generated to illustrate key parameters such as motor speeds, orientation angles, and stability metrics. Data analysis revealed trends and patterns in the mechanism's behavior under different conditions, facilitating a deeper understanding of its dynamics and performance characteristics. Statistical analysis provided quantitative measures of stability, agility, and robustness, allowing for objective evaluation and comparison of different control strategies and design configurations.

Fig. 14 Data visualization of the data collected from MPU6050 while implementing PID control on BLDC motors

7) Limitations and Future Work:

Despite the overall success of the experimental validation, certain limitations and areas for improvement were identified. For instance, the mechanism's performance may be affected by external factors such as wind, uneven terrain, or mechanical wear over time. Additionally, further optimization of the control algorithm and mechanical design could enhance stability and agility even further. Future work could focus on implementing advanced control strategies, such as model predictive control or reinforcement learning, to further improve the mechanism's performance in dynamic environments. Additionally, research into novel materials and actuation systems could lead to lighter, more energy-efficient designs with improved durability and longevity.

In conclusion, the results and analysis of the experimental validation demonstrate the effectiveness, stability, and robustness of the torso balancing mechanism for bipedal walking robots. Through careful testing and analysis, valuable insights were gained into the mechanism's performance characteristics, paving the way for further advancements in bipedal robotics and autonomous locomotion.

#### 6. CONCLUSION

The development and validation of the torso balancing mechanism for bipedal walking robots represent a significant advancement in the field of robotics. Through a comprehensive methodology encompassing dynamical modeling, mechanical design, component selection, controller design, experimental validation, and interpretation of results, valuable insights have been gained into the performance, stability, and agility of the mechanism.

The successful implementation of the torso balancing mechanism has demonstrated its ability to achieve and maintain stability and balance during stationary and dynamic tasks. By leveraging advanced control algorithms and mechanical designs, the mechanism can autonomously adjust motor speeds to counteract gravitational and inertial forces, ensuring the robot remains upright and stable even in challenging environments. This achievement has profound implications for bipedal robotics, enhancing the usability, safety, and versatility of robots operating in real-world scenarios.

Furthermore, the rapid response time and agility exhibited by the mechanism enable it to react quickly to external disturbances and adjust motor speeds accordingly. This agility is essential for navigating obstacles, negotiating uneven terrain, and adapting to changing environmental conditions, enhancing the robot's autonomy and effectiveness in dynamic environments. The mechanism's robustness to disturbances further enhances its reliability and adaptability, enabling robots to withstand external forces and maintain stability under challenging conditions.

Additionally, the energy efficiency demonstrated by the mechanism optimizes power consumption and battery usage, extending operational periods and reducing the need for frequent recharging or battery replacement. This energy efficiency is crucial for applications requiring prolonged operation or missions in remote or inaccessible areas, enhancing the overall effectiveness and utility of bipedal walking robots.

The interpretation of the experimental results has provided valuable insights into the implications of the findings for the field of robotics. By highlighting achievements, challenges, and opportunities for future research and development, this section contributes to the ongoing advancement of bipedal robotics and autonomous locomotion. Further optimization of the control algorithm and mechanical design, coupled with research into advanced control strategies, novel materials, and actuation systems, holds promise for unlocking new possibilities in bipedal locomotion and autonomous navigation.

In conclusion, the development and validation of the torso balancing mechanism represent a significant step forward in the quest to create robust, agile, and energy-efficient bipedal walking robots. Through careful design, experimentation, and analysis, the mechanism has demonstrated its potential to enhance the capabilities of robots operating in a wide range of environments and applications. As research in this field continues to evolve, the insights gained from this work will pave the way for future advancements in bipedal robotics and autonomous systems, ultimately leading to more capable and versatile robots that can assist humans in various tasks and environments.

#### 7. FUTURE SCOPE

The successful development and validation of the torso balancing mechanism for bipedal walking robots lay the groundwork for exciting future advancements and innovations in the field of robotics. As technology continues to evolve and research progresses, several promising avenues emerge for further exploration and development:

1) Advanced Control Strategies:

Future research could focus on the exploration and implementation of advanced control strategies to further enhance the performance and capabilities of bipedal walking robots. Machine learning techniques, such as reinforcement learning and neural networks, offer the potential to develop adaptive and intelligent control systems that can learn from experience and optimize performance in real-time. By leveraging data-driven approaches, robots can adapt to changing environments, learn from interactions, and continuously improve their locomotion and balance capabilities.

2) Soft Robotics and Biomimicry:

The integration of principles from soft robotics and biomimicry holds promise for creating robots with enhanced agility, flexibility, and resilience. Drawing inspiration from nature, researchers can design soft, compliant actuators and structures that mimic the flexibility and adaptability of biological systems. By emulating the biomechanics of animals like humans and animals, robots can achieve more natural and efficient movement, enabling them to navigate complex environments and perform tasks with greater dexterity and precision.

3) Multi-modal Sensing and Perception:

Advancements in sensor technology and perception algorithms offer opportunities to enhance robots' situational awareness and environmental understanding. Integrating multi-modal sensing capabilities, such as vision, LiDAR, and tactile sensing, enables robots to perceive and interpret their surroundings more comprehensively. By combining sensor data with advanced perception algorithms, robots can detect obstacles, plan optimal paths, and interact safely and intelligently with humans and other objects in their environment.

4) Human-Robot Collaboration and Interaction:

The development of robots capable of collaborating and interacting seamlessly with humans opens up new possibilities for applications in various domains, including healthcare, manufacturing, and assistive robotics. Future research could focus on designing intuitive and natural interfaces for human-robot interaction, enabling robots to understand and respond to human commands, gestures, and expressions effectively. By fostering collaboration between humans and robots, we can harness the strengths of both to accomplish complex tasks more efficiently and safely.

5) Autonomous Navigation and Exploration:

Advancements in autonomy and navigation algorithms enable robots to operate more independently and intelligently in dynamic and unstructured environments. Future research could focus on developing robust localization, mapping, and path planning algorithms that enable robots to navigate complex terrains, avoid obstacles, and explore unknown environments autonomously. By equipping robots with the ability to autonomously navigate and explore, we can unlock new capabilities for applications such as search and rescue, environmental monitoring, and space exploration.

6) Ethical and Societal Implications:

As robots become increasingly integrated into society, it is essential to consider the ethical and societal implications of their deployment. Future research could explore questions related to safety, privacy, autonomy, and human-robot interaction ethics. By addressing these challenges proactively, we can ensure that robots are developed and deployed in a responsible and ethical manner, benefiting society while minimizing potential risks and unintended consequences.

In conclusion, the future of bipedal walking robots holds immense promise, with opportunities for advancements in control, sensing, interaction, autonomy, and ethics. By continuing to push the boundaries of innovation and collaboration across disciplines, researchers can unlock new capabilities and applications for bipedal robots, ultimately leading to a future where robots play a transformative role in enhancing human productivity, safety, and quality of life.

APPENDIX A - ACRONYMS AND ABBREVATIONS

BLDC: Brushless DC

PID: Proportional-Integral-Derivative

ESC: Electronic Speed Controller

LiPo: Lithium Polymer

IMU: Inertial Measurement Unit

MEMS: Micro-Electro-Mechanical Systems

RC: Radio Control

MPU6050: Inertial Measurement Unit model number

PSO: Particle Swarm Optimization

CAD: Computer-Aided Design

3D: Three-Dimensional

I2C: Inter-Integrated Circuit

LiDAR: Light Detection and

APPENDIX B - GLOSSARY

- BLDC: Brushless DC - A type of motor that operates without brushes, commonly used in robotics and RC vehicles for its efficiency and reliability.
- PID: Proportional-Integral-Derivative - A control algorithm used to regulate system behavior by calculating the error between desired and measured values and adjusting control inputs accordingly.
- ESC: Electronic Speed Controller - Device used to control the speed and direction of electric motors, commonly used in RC vehicles and drones.
- LiPo: Lithium Polymer - A type of rechargeable battery known for its high energy density and lightweight design, commonly used in drones, RC vehicles, and robotics.
- IMU: Inertial Measurement Unit - A sensor module that measures and reports a body's specific force, angular rate, and sometimes the magnetic field surrounding the body.
- MEMS: Micro-Electro-Mechanical Systems - Miniature integrated devices or systems that combine mechanical and electrical components fabricated using integrated circuit (IC) fabrication techniques.
- RC: Radio Control - A technology that allows remote control of devices through radio signals, commonly used in model airplanes, cars, boats, and drones.
- MPU6050: Inertial Measurement Unit model number - A specific model of IMU commonly used in robotics and motion sensing applications.
- PSO: Particle Swarm Optimization - An optimization algorithm inspired by the social behavior of bird flocking or fish schooling.
- CAD: Computer-Aided Design - The use of computer systems to assist in the creation, modification, analysis, or optimization of a design.
- 3D: Three-Dimensional - Having three dimensions of length, width, and height, commonly used in reference to objects or models created using CAD software.
- I2C: Inter-Integrated Circuit - A synchronous, multi-master, multi-slave, packet-switched, single-ended, serial communication bus commonly used in embedded systems and electronic devices.
- LiDAR: Light Detection and Ranging - A remote sensing method that uses light in the form of a pulsed laser to measure variable distances to the Earth, commonly used in robotics, surveying, and autonomous vehicles.

BIBLIOGRAPHY

- https://idsc.ethz.ch/content/dam/ethz/special-interest/mavt/dynamic-systems-n-control/idsc-dam/Research_DAndrea/Cubli/Cubli_IROS2012.pdf
- https://spectrum.ieee.org/balancing-robot-cube
- https://www.mdpi.com/2227-7390/8/10/1840
- https://www.irjet.net/archives/V7/i7/IRJET-V7I7232.pdf
- https://www.researchgate.net/publication/317079231_Design_and_Implementation_of_Ball_and_Beam_System_Using_PID_Controller
- https://www.diva-portal.org/smash/get/diva2:1373784/FULLTEXT01.pdf.
- A. Stephenson, “On a new type of dynamical stability,” Proceedings: Manchester Literary and Philosophical Society, vol. 52, pp. pp. 1–10, 1908.
- P. Reist and R. Tedrake, “Simulation-based lqr-trees with input and state constraints,” in Robotics and Automation (ICRA), 2010 IEEE International Conference on, may 2010, pp. 5504 –5510.
- D. Alonso, E. Paolini, and J. Moiola, “Controlling an inverted pendulum with bounded controls,” in Dynamics, Bifurcations, and Control, ser. Lecture Notes in Control and Information Sciences. Springer Berlin / Heidelberg, 2002, vol. 273, pp. 3–16.
- M. V. Bartuccelli, G. Gentile, and K. V. Georgiou, “On the stability of the upside-down pendulum with damping,” Proceedings: Mathematical, Physical and Engineering Sciences, vol. 458, no. 2018, pp. pp. 255–269, 2002.
- J. Meyer, N. Delson, and R. de Callafon, “Design, modeling and stabilization of a moment exchange based inverted pendulum,” in 15h IFAC Symposium on System Identification, Saint-Malo, France, 2009, pp. 462 – 467.

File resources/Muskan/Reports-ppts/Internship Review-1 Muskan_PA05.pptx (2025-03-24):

## An Internship Report Review-1

- Final Year(2020-2024)
- By
- Muskan Patel (PA-05)
- PRN - 1032200264
- Branch: Mechanical Engg.
- Guide: Asst. Prof. Ashish Pawar

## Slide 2

CONTENT

1. Introduction of Company
2. Department of work & Role
3. Internship Plan and Daily tasks
4. Projects/ Problem Statements and Solutions
5. References

## INTRODUCTION OF COMPANY

IIT Bombay: India's Premier Technical University
- Established in 1958 with foreign assistance.
- Received UNESCO funds from the Soviet Union.
- Designated an 'Institute of National Importance' by Parliament in 1961.
- Governed by a board of governors, chaired by the president of India.
- Operates under the guidance of the IIT Council, established by India's Ministry of Education.
- Known for excellence in engineering education and research.
- Offers innovative short-term courses, continuing education, and distance learning.
- Faculty members have received prestigious awards.
- Located in Powai, Mumbai offering a residential experience.

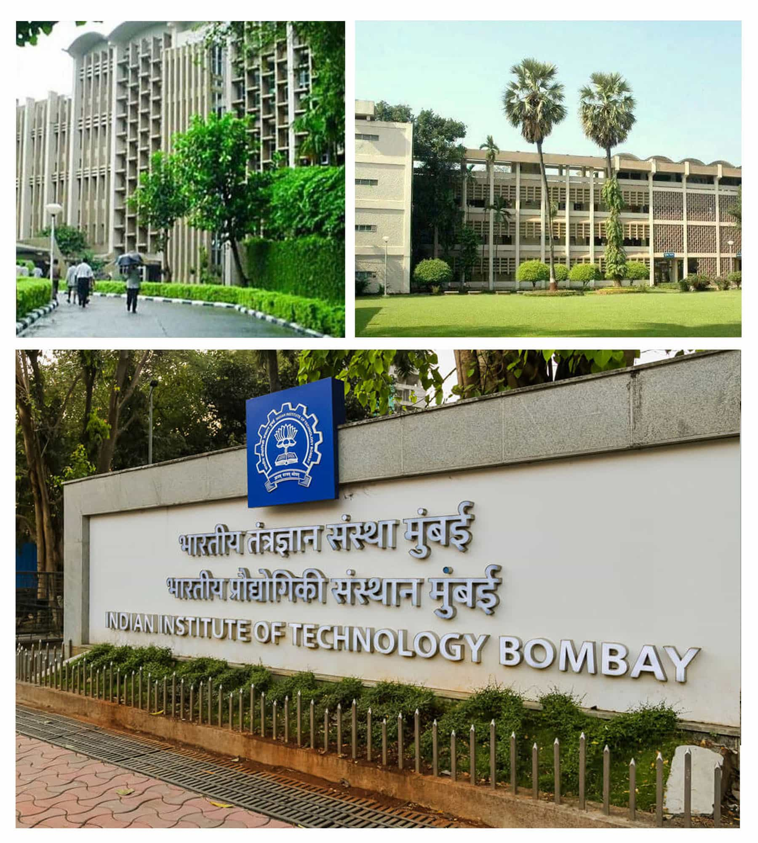
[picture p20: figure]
IIT Bombay Announces PhD Admission for Spring Semester 2022-23

## DEPARTMENT AND ROLE

- I am currently serving as a research intern in the Department of Mechanical Engineering, where I report to Prof. Vivek Sangwan, the esteemed professor in the department of mechanical engineering at IITB.
- My responsibilities encompass a balanced blend of CAD designing and testing of mechanisms in balancing a torso of bipedal walking robot.
- My typical workday spans 8 and half hours, providing flexibility within the timeframe of 9:30 AM to 6:00 PM to accommodate various testing and development activities. Internship Duration is of 4 months.
- At the end of each project , a comprehensive report must be written in order to conclude the project successfully or to further improvise it.

## PROBLEM STATEMENTS

- To obtain the dynamical equations of the balanced link and simulate the system using MATLAB.
- To design a torso balancing mechanism using solidworks.
- Manufacture the biped and perform torso attitude control and also implement controller.
- Integrating this system with the ankle impulse delivery mechanism.

## WEEK-1

- Introduction to IITB, goals, mission and vision of the mechanical engineering and the dedicated project.
- Glimpse of ongoing project (Design and manufacturing of bipedal walking robot).
- Collected 10 research papers based on three major concepts:
1. Cubli
2. Flywheels
3. Biped

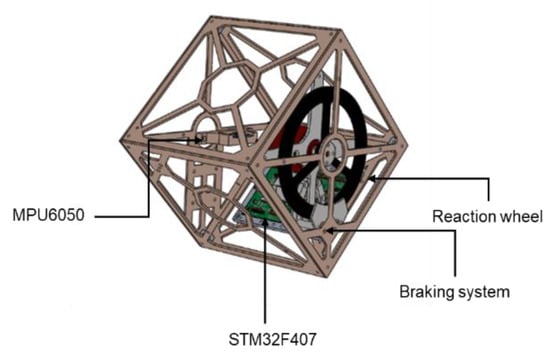
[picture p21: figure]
Mathematics | Free Full-Text | Nonlinear Dynamics and Control of a Cube Robot

## WEEK-2

- Derived the equation to find the radius of the flywheel depending on the frame inertia as to balance the frame, the moment of inertia of frame should be equal to the inertia of the flywheel.
- Derived the dynamical equations of an inertia wheel on which torque is applied. Also, learnt the basics of ODE45 solver in MATLAB by simulating the derived equation in MATLAB using ode45 and pd controller.

## WEEK-3

- Started with the solidworks design of the parts involved in the complete desired biped system. Successfully made major parts of the biped which are the three links – two being 2040 aluminum profiles and one is the frame also called torso which will have two BLDC motors mounted over its diagonal extreme ends.
- Understood the basics of the XEP100 microcontroller by studying the pins and functions of them using the datasheet given. Also, understood that to balance the torso the speed and direction control of motor is the most important part.
- Successfully derived the dynamical equations of the given system using two methods to verify them simultaneously. Also, verified both of the equations.

## WEEK-4

- Successfully interfaced the potentiometer with XEP100 and also understood the concept of analog to digital converter.
- Firstly, performed energy check by keeping the system torque=0 first, then torque=constant and then a sine function. The equations are hence verified and then simulated the system.
- All the parts of the system are designed and also started with the assembly, deciding the size of nuts and bolts, angle joints and bearings.

## WEEK-5

- Finalized the design after making the required changes in the cad.
- Read about PWM signal and understood the purpose of PWM and also that it will be used in motor speed and direction control.
- Successfully completed the given task and plotted the PWM signals with different duty cycles on oscilloscope.

## WEEK-6

- Started with the finalization of the parts of the complete biped model.
- Worked on the equation derivation of the given system using lagrangian method first but encountered few issues then also derived equations using newton’s method but obtained two different equations of same system by two different methods.

## WEEK-7

- Found the error and resolved the equations and obtained the output as required in the matlab ode45.
- Started with interfacing Arduino uno with BLDC motor and Simonk 30A ESC, potentiometer and MPU 6050 gyroscope individually first. Also, got familiar with Teensy 4.1 microcontroller to replace Arduino uno with Teensy 4.1 later.

## REFERENCES

1. https://www.iitb.ac.in/safety/en/about-iit-bombay (https://ethz.ch/content/dam/ethz/special-interest/mavt/dynamic-systems-n-control/idsc-dam/Research_DAndrea/Cubli/Cubli_IROS2012.pdf)
2. https://ethz.ch/content/dam/ethz/special-interest/mavt/dynamic-systems-n-control/idsc-dam/Research_DAndrea/Cubli/Cubli_IROS2012.pdf
3. https://www.mdpi.com/2226-4310/8/9/252
4. https://www.researchgate.net/publication/224323192_Satellite_attitude_control_using_three_reaction_wheels
5. https://in.mathworks.com/help/matlab/ref/ode45.html
6. https://media.digikey.com/pdf/Data%20Sheets/Adafruit%20PDFs/4622_Web.pdf
7. https://invensense.tdk.com/wp-content/uploads/2015/02/MPU-6000-Datasheet1.pdf
8. https://www.rhydolabz.com/documents/26/BLDC_A2212_13T.pdf

## THANK YOU!!

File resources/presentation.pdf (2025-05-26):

# Bachelor Thesis Project - 2 Attitude Control of One DOF Drone

### Kushal Agarwal

210100087

### Guide: Prof. Vivek Sangwan

Department of Mechanical Engineering,

### Indian Institute of Technology Bombay

## Introduction and Objective

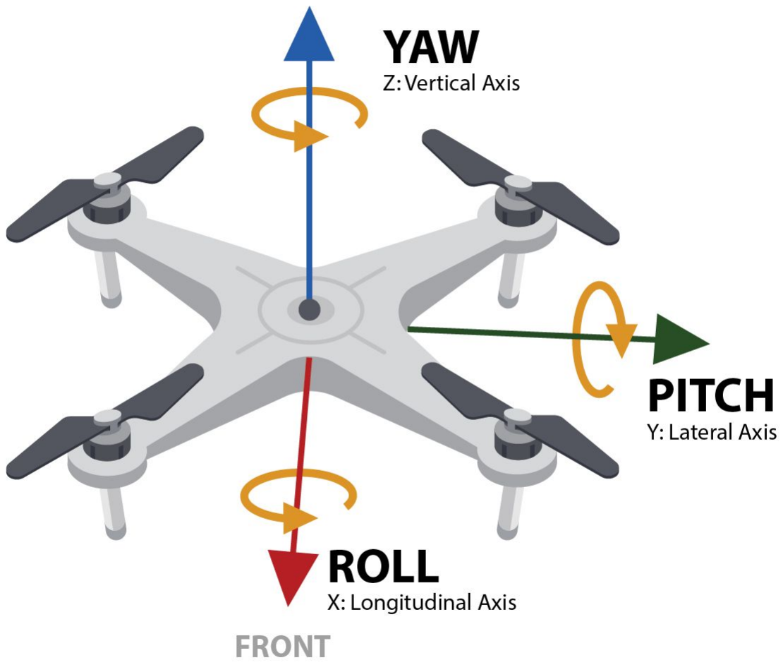
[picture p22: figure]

Attitude control refers to the control of the orientation and position of an object in 3D space

Applications:
- Coupled dynamics of aerial vehicles/submarines
- Balancing boards for rehabilitation
- Robots for maintaining orientation
- In defense for guided missiles

Learning Outcomes:
- Non-linear coupled dynamics control
- Nested loop controller
- Dynamics simulation

Attitude
nomenclature

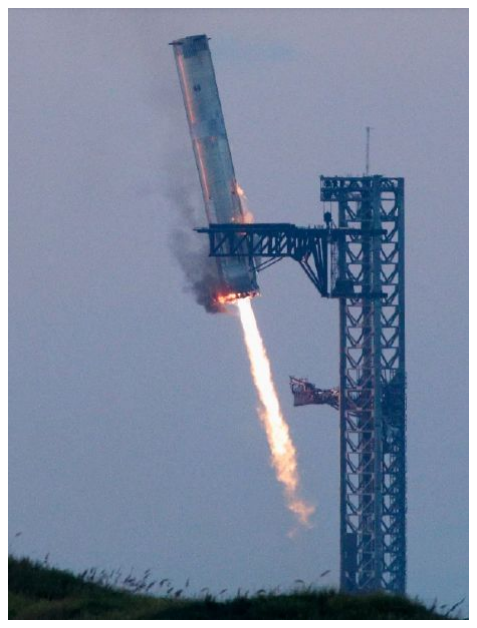
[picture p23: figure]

SpaceX rocket booster

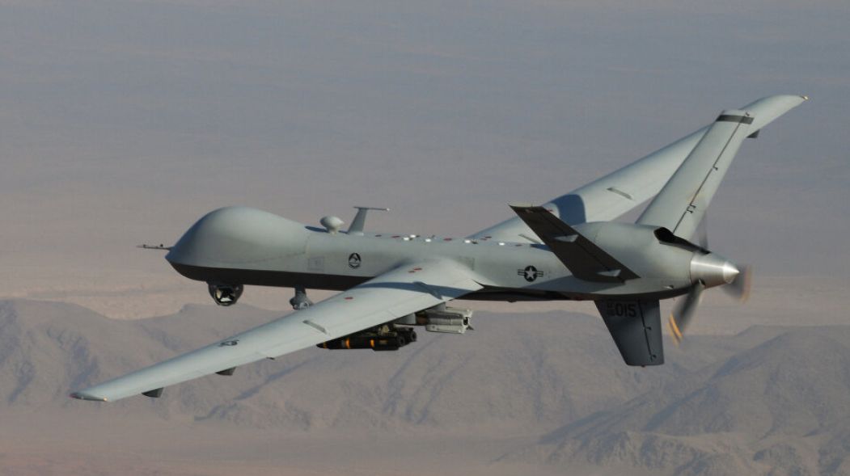
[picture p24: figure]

MQ-9 Reaper of US Air Force

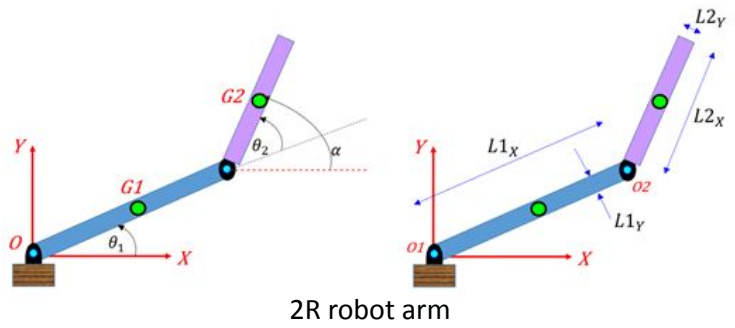
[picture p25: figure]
2R robot arm

Kinematics | Energies | Dynamics
State Space | Controller
| | Proportional Integral Derivative Controller

## Understanding Simulation - 2R Robot Arm

Objective:
- Understanding dynamics derivation using Lagrange Equation
- Simulation of a real system using ode45
- Designing, implementing and tuning controllers for a given system

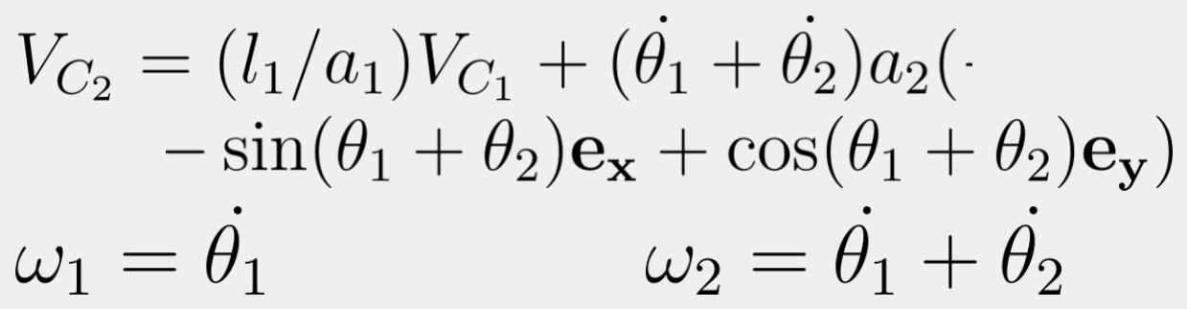
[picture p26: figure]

## Understanding Simulation - 2R Robot Arm

- ode45 was used to simulate the system and a PID controller was used for setpoint and trajectory tracking
- Momentum was calculated both, from torque integration and velocities for verification


Total energy of a freely falling system


Difference in total energy calculated from momentum integration and kinematics

## 1D balancing - Mechanics

Kinematics:; Dynamics:; Kinetic Energy:; Potential Energy:; Lagrange:; Euler Lagrange Equation:; Upon solving,

A one dimensional balancing robot free to rotate about ground contact point

## 1D balancing - Mechanics

Constraints:

Robot is always in touch with the ground

Only one point of the robot is in contact with the ground

Propellers can produce thrust in one direction


Solution Space:

## Physical Model

2020T Aluminum profile; IMU for feedback; BLDC motors; 3D printed Hub; ESCs

Low thrust propellers

Teenzy microcontroller
for high rate control loop
with required I/O
interface

Acrylic for mounting
electronics

Stoppers to protect
the robot when at
rest

PLA FDM printed
motor mounts

Estimated as line contact. Rubber is used to provide friction and prevent yaw.

LiPo battery

## Physical parameters

## Hardware


## Hardware


## Controller


PD controller:
Error dynamics

Commanded acceleration

Commanded thrust

With Constraints:

Green line is a solution
of the PD controller
without constraints.
Blue line is a solution
of the PD controller
with constraints

Taking into account:

1. Normal Contact > 0
2. Thrust > 0

Solution space for
varying u_0

## Controller: Existence of a solution


Since u_d depends only on controller gains and trajectory inputs, we try to constrain them so that the controller is always able to find a solution

- For a given orientation, the red and green lines represent the maximum and minimum possible values of u_d permissible
- To guarantee a solution, we will restrict u_d to inside the green circle
- Analytical solution for radius of the green circle does not exist
- With numerical estimates and trajectory acceleration bounds, estimate Kp and Kd

Saturation of thrust is required

Solution space of u_d as a function of time

Required saturation of u_0

## Controller: Saturation

u_0 is saturated the prevent individual thrusts to cross the constraints.

Saturation function requirements:
- Linear to a large extent
- C0 and C1 continuity for smooth trajectories
- Asymptotically approaching saturation limits

Exponential function is chosen with linearity in central region


Exponential saturation of u_0


Exponential saturation function


## Controller: Selecting Optimal Gains


Optimizing power requirements:

- We want atleast ε fraction of power in each motor for propellers to run
- We want atleast β fraction of power to be available on each side of the operating point
- Since power is non-linear in thrusts and interpolating power to get thrust is computationally heavy, we will approximate our power
requirements to vary linearly with
thrusts Minimum and maximum power points

Identification of operating point

## Controller implementation


## Results: Simulation


Results from trajectory tracking simulation in MATLAB:

- ode45 used for system simulation
- 0.5Hz sinusoidal trajectory requirement
- Non zero initial conditions
- We observe thrusts are always positive and much lesser than weight
- Thrusts get saturated for low requirements
- Continuous variation of thrusts but with abrupt change in jerk
- Kinetic energy has lower magnitude oscillations compared to potential energy
- Tracking catches up in ~1s

# Results: Static Thrust Test


# Results: Hardware


# Results: Hardware


## Future Work

## - Increase Propeller size

## - Use Simulated Control Law

## - Implement Yaw Control

# Understanding Simulation - 2R Robot Arm


## ode45 was used to simulate the system and a PID controller was used for setpoint

and trajectory tracking.

## Dynamics:

State Space:

## Momentum was calculated both, from torque integration and velocities for verification

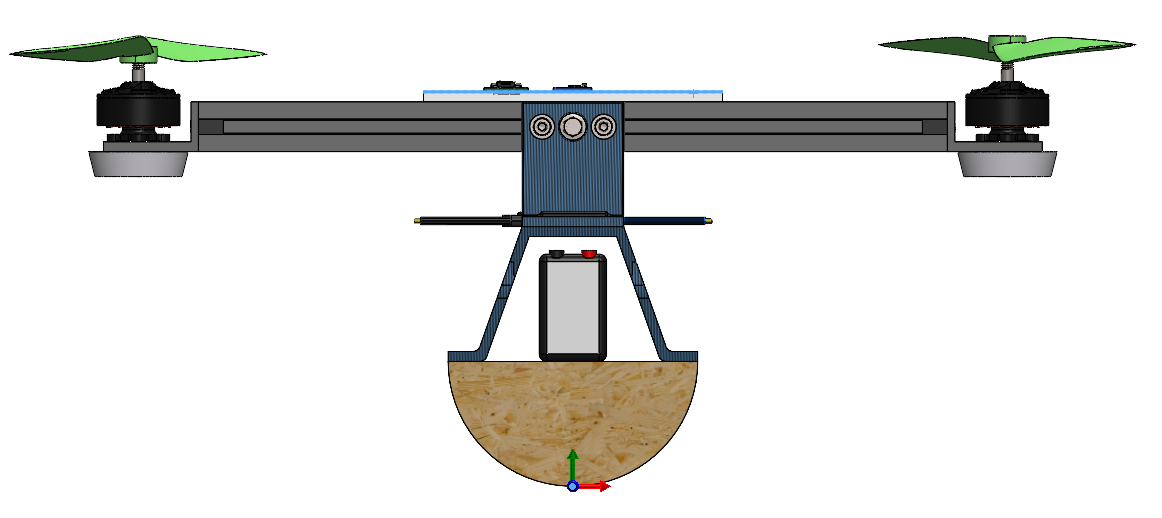
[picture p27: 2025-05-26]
hardware/cad/2D.png

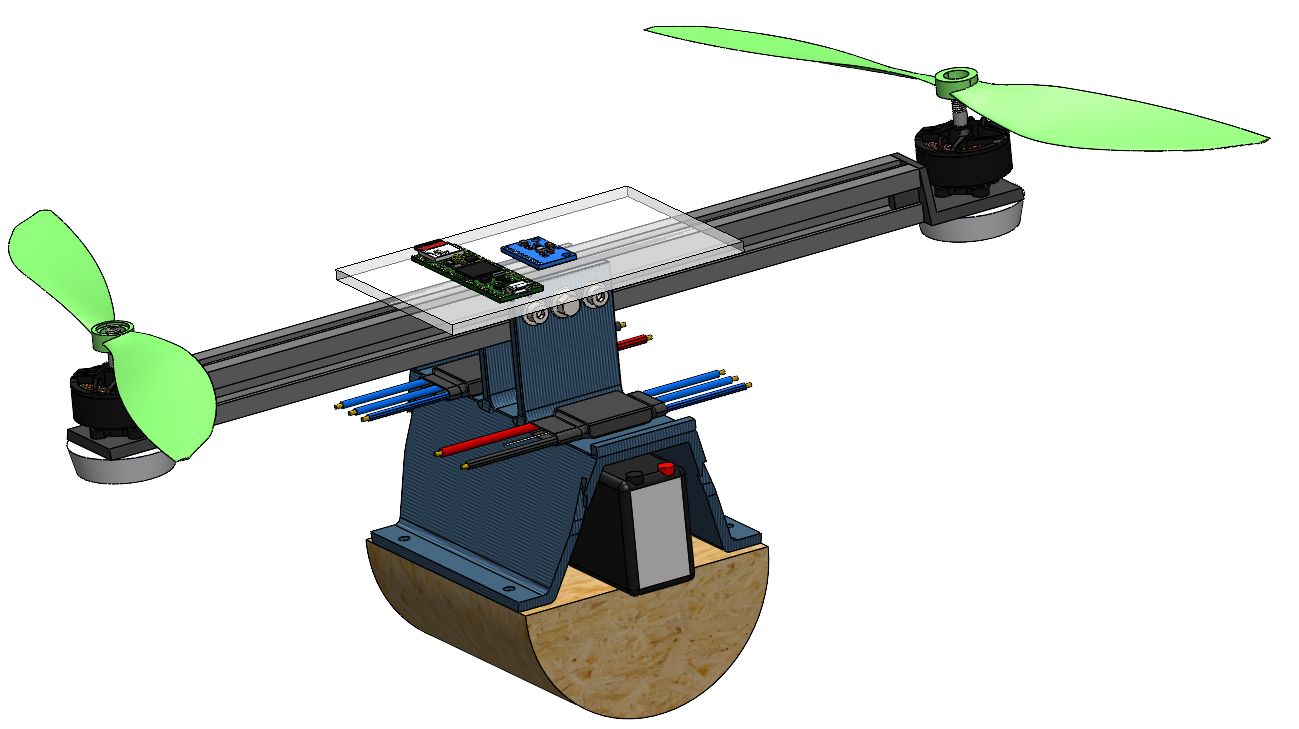
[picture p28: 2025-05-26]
hardware/cad/full_view.png

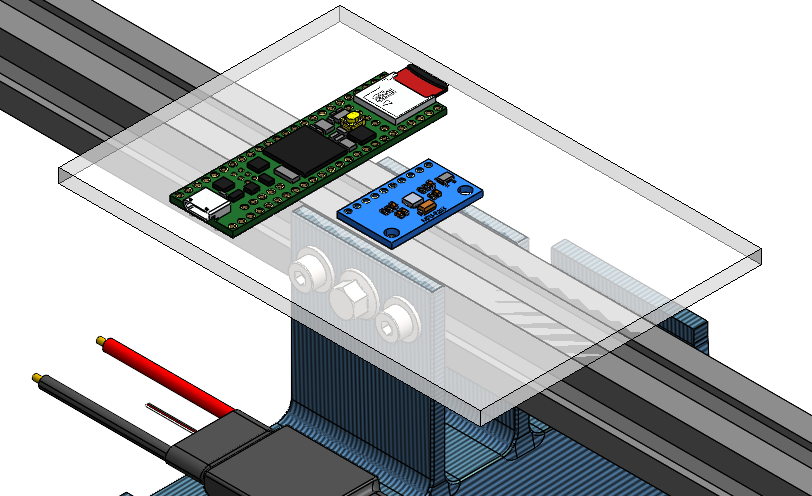
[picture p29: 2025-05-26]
hardware/cad/top_plate.png

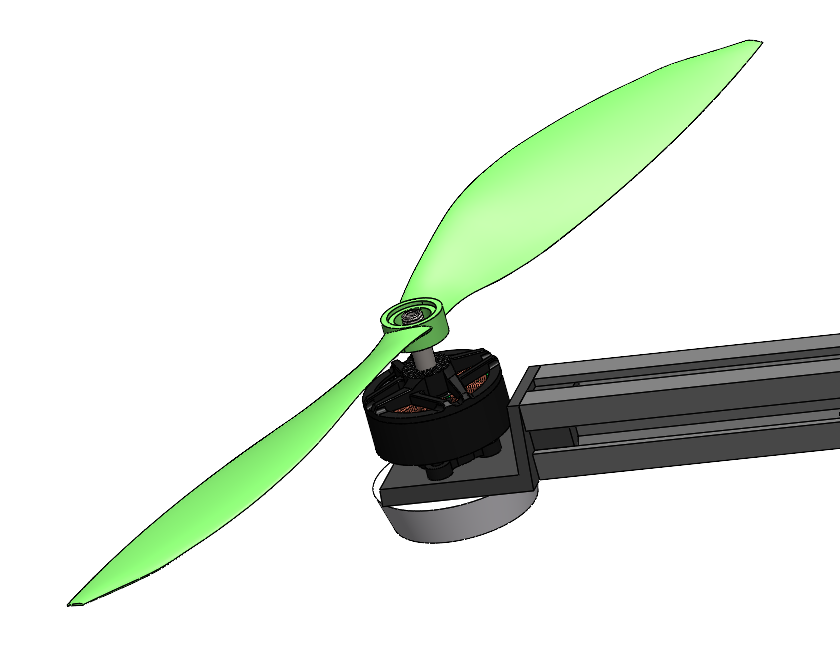
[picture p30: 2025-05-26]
hardware/cad/motor_propellor.png

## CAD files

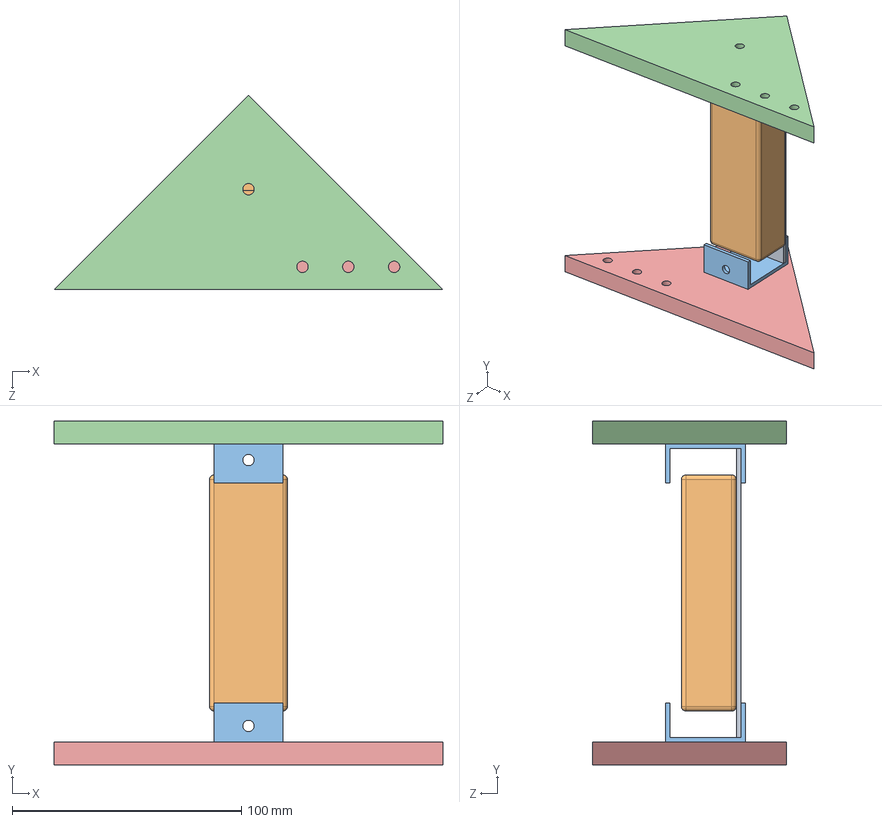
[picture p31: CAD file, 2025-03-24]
resources/Muskan/CAD/battery_setup.SLDASM
169.7 x 150.0 x 84.9 mm
battery_mount
Turnigy_2200mAh_3S_20C_Lipo_Pack
battery_clamp x 2
side_frame
side_frame - Copy

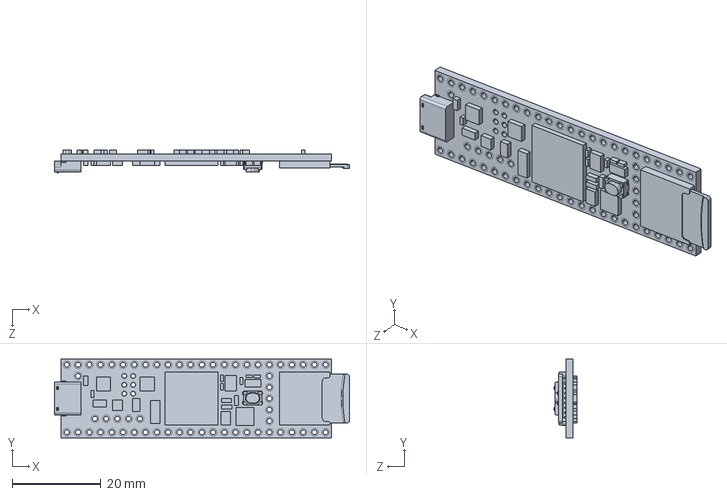
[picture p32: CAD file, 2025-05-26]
hardware/cad/Teensy_4.1_Assembly.SLDPRT
66.6 x 17.8 x 5.27 mm

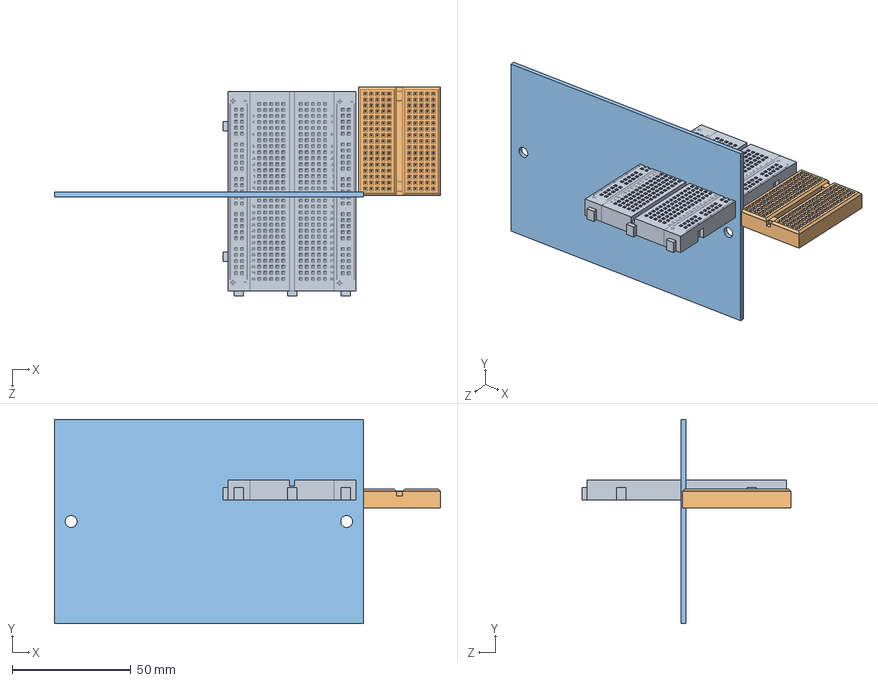
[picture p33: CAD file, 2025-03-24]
resources/Muskan/CAD/breadboard setup.SLDASM
162.5 x 86.0 x 87.9 mm
halfBreadboard 400.stp
MiniBreadboard
breadboard_mount

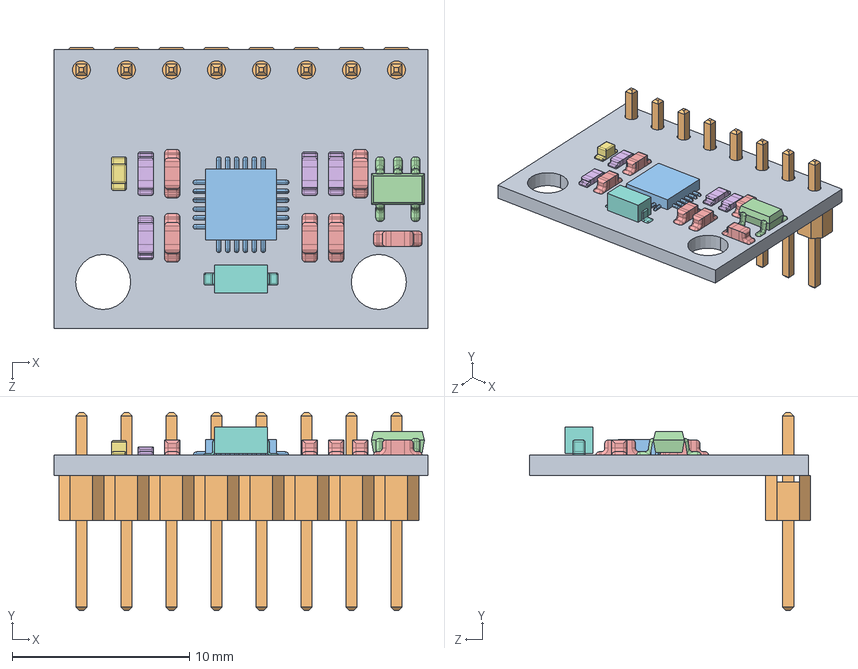
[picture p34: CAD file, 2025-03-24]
resources/Muskan/CAD/MPU 6050 IMU.SLDASM
21.1 x 11.2 x 15.9 mm
Base.STEP
pin header.STEP x 8
sensor chip.STEP
S2NH chip.STEP
Resistor small.STEP x 6
Resistor small black.STEP x 4
Small LED.STEP
Resistor black.STEP

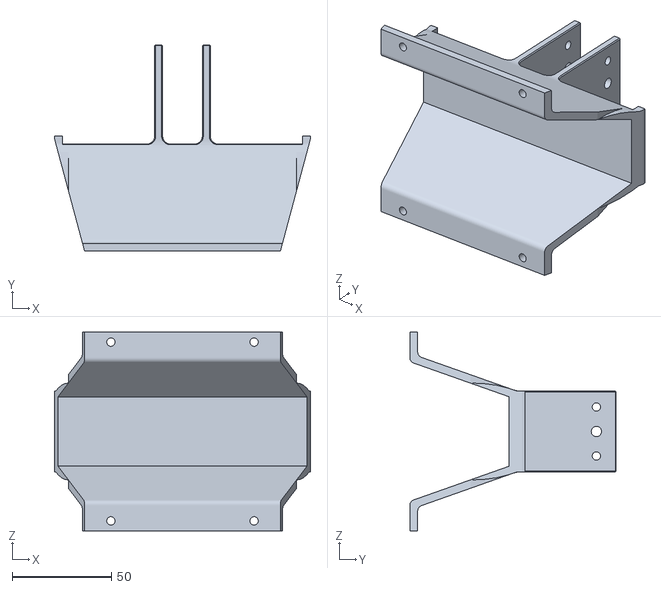
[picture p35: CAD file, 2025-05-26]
hardware/cad/Part2^second try.STL
128.9 x 104.0 x 100.0

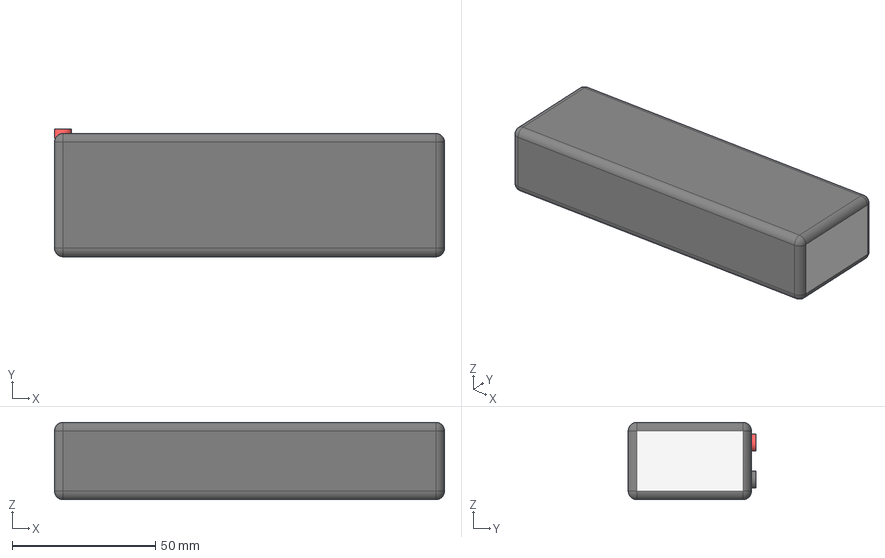
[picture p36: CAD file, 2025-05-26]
hardware/cad/LIPO.stp
136.0 x 44.5 x 27.0 mm

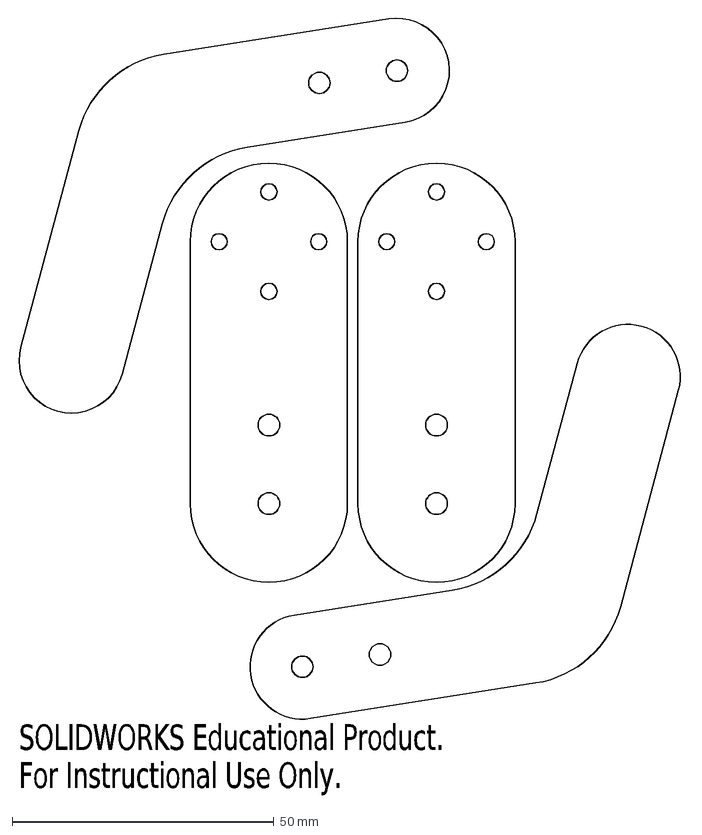
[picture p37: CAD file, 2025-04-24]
hardware/laser cut/mounts.DXF
SOLIDWORKS Educational Product.
For Instructional Use Only.

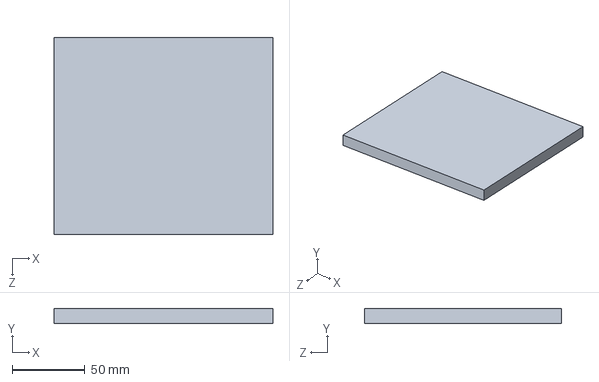
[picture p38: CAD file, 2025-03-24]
resources/Muskan/CAD/bottom_frame.SLDPRT
150.0 x 10.0 x 135.0 mm

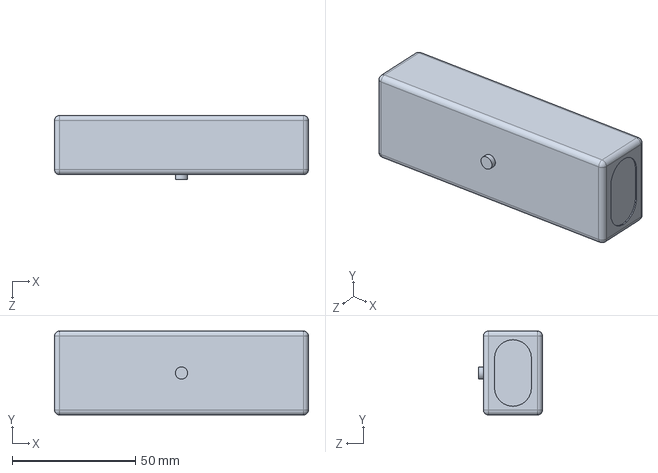
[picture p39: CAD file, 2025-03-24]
resources/Muskan/CAD/Turnigy_2200mAh_3S_20C_Lipo_Pack.SLDPRT
103.0 x 34.0 x 26.0 mm

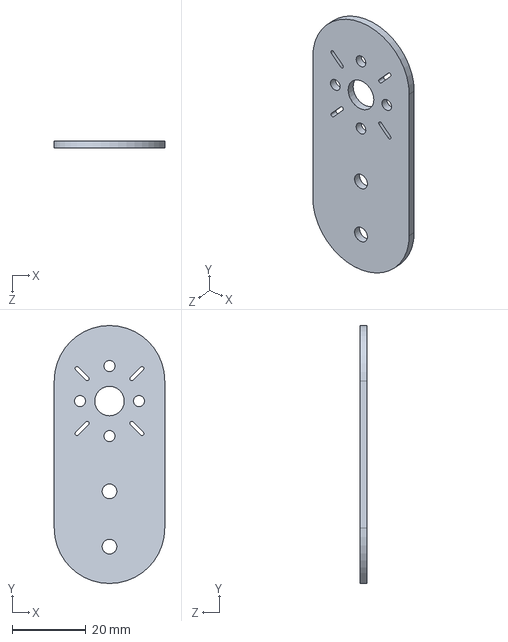
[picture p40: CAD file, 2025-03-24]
resources/Muskan/CAD/motor_mount.SLDPRT
30.0 x 70.0 x 2.00 mm

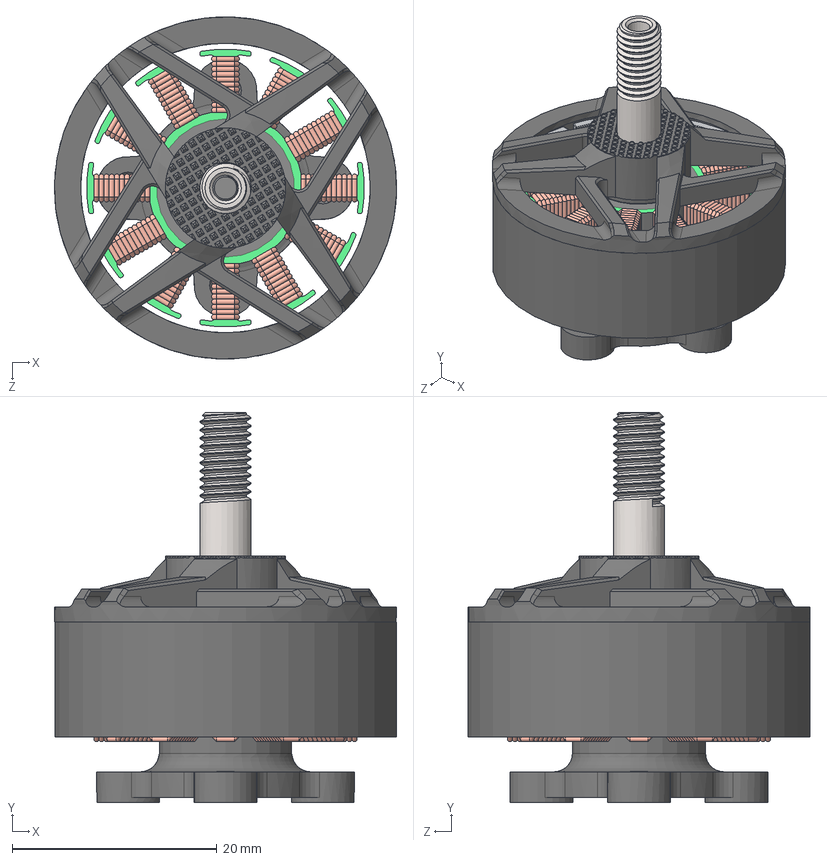
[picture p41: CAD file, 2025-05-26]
hardware/cad/T-Motor F100 2810 KV1350 5-6S Motor.STEP
33.4 x 38.0 x 33.4 mm
T-Motor F100 2810 KV1350 Stator
F100 - 964 Bearing_7804K101 x 2
MMC-91239A110 M3 x 5mm Button Head Hex Drive Screw_91239A110
T-Motor F100 2810 KV1350 Rotor

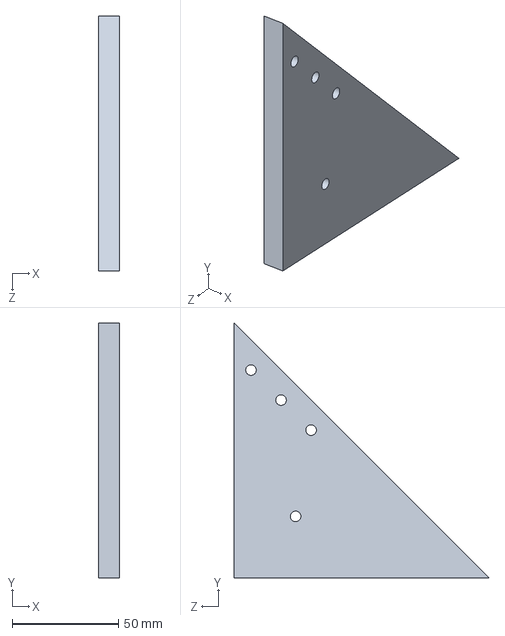
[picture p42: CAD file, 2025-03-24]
resources/Muskan/CAD/side_frame.SLDPRT
10.0 x 120.0 x 120.0 mm

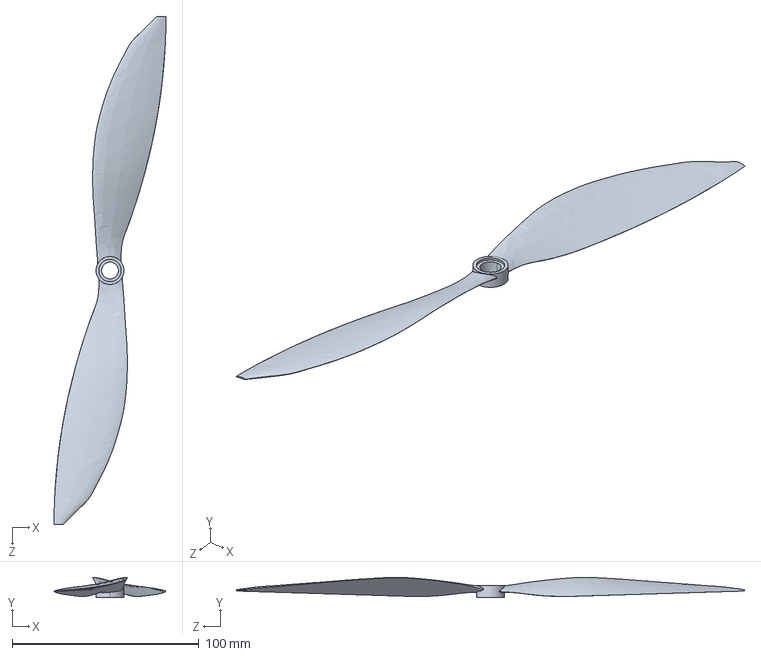
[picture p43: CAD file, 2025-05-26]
hardware/cad/11x4.7_9mm.STEP
60.0 x 10.8 x 272.4 mm

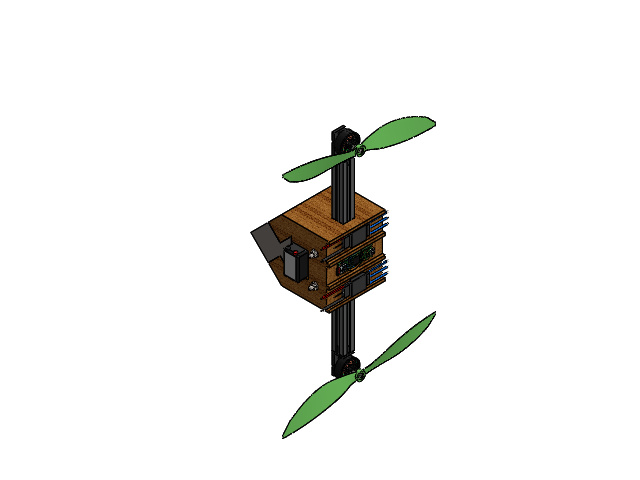
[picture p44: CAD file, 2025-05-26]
hardware/cad/first try.SLDASM
metal end tip^first try
main body^first try
LIPO
2020T
continous stud_am x 2
hex flange nut_am x 4
Teensy_4.1_Assembly
PCB, MPU-9255.STEP
SMD Resistor, 10kO, MPU-9255.STEP x 5
SMD Capacitor, MPU-9255_14 _F.STEP x 3
SMD Capacitor, MPU-9255_10 _F.STEP
SMD Capacitor, MPU-9255_120 nF.STEP
MPU-9255 IC.STEP
MIC5205 Low Noise LDO, MPU-9255.STEP
Tantalum Capacitor, 15uF, MPU-9255.STEP
motor_mount x 2
T-Motor F100 2810 KV1350 Stator.STEP x 2
F100 - 964 Bearing_7804K101.STEP x 4
MMC-91239A110 M3 x 5mm Button Head Hex Drive Screw_91239A110.STEP x 2
T-Motor F100 2810 KV1350 Rotor.STEP x 2
11x4.7_9mm
Mirror11x4.7_9mm
30A ESC x 2

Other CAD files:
hardware/cad/second try.SLDASM
hardware/cad/MPU-9255 sensor.SLDASM
hardware/laser cut/Part1.SLDPRT
hardware/cad/Mirror11x4.7_9mm.SLDPRT
hardware/cad/11x4.7_9mm.SLDPRT
hardware/cad/2020T.SLDPRT
hardware/cad/30A ESC.SLDPRT
hardware/cad/LIPO.SLDPRT
hardware/cad/MPU-9255.SLDASM
hardware/cad/MPU-9255.STEP
hardware/cad/T-Motor F100 2810 KV1350 5-6S Motor.SLDASM
hardware/cad/motor_mount.SLDPRT
resources/Muskan/CAD/2020 alu section_100.SLDPRT
resources/Muskan/CAD/2020 alu section_vertical.SLDPRT
resources/Muskan/CAD/30A ESC SimonK Firmware.SLDPRT
resources/Muskan/CAD/MiniBreadboard.SLDPRT
resources/Muskan/CAD/battery_clamp.SLDPRT
resources/Muskan/CAD/battery_mount.SLDPRT
resources/Muskan/CAD/breadboard_mount.SLDPRT
resources/Muskan/CAD/clamp.SLDPRT
resources/Muskan/CAD/motorplate.SLDPRT
resources/Muskan/CAD/side_frame - Copy.SLDPRT
resources/Muskan/CAD/top_frame.SLDPRT

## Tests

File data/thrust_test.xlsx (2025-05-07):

motor L
V = 11.2V
Test 2
PWM (%) | weight reading (g)
0 | 0
10 | 22
15 | 32
20 | 46
25 | 60
30 | 81
35 | 102
40 | 120
Test 3
PWM (%) | weight reading (g) | current (A)
0 | 0 | 0.12
10 | 22 | 0.36
15 | 32 | 0.49
20 | 46 | 0.66
25 | 60 | 0.85
30 | 81 | 1.13
35 | 102 | 1.51
40 | 120 | 1.88
Test 4
PWM (%) | weight reading (g) | current (A)
0 | 0 | 0.1
10 | 20 | 0.3
15 | 32 | 0.5
20 | 46 | 0.6
25 | 61 | 0.8
30 | 78 | 1.1
35 | 102 | 1.4
40 | 120 | 2
45

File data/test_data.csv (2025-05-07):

Timer | Angle | AngleRate | Error | ErrorRate | P | I | D | PID | velL | velR
0 | -23.36 | 1.69 | 23.36 | -1.69 | 32.71 | 0.01 | 2.03 | 34 | 34 | 0
1 | -23.43 | 0.87 | 23.43 | -0.87 | 32.81 | 0.02 | 0.00 | 32 | 32 | 0
2 | -23.42 | 0.87 | 23.42 | -0.87 | 32.79 | 0.03 | 0.00 | 32 | 32 | 0
3 | -23.72 | 0.85 | 23.72 | -0.85 | 33.20 | 0.04 | 0.00 | 33 | 33 | 0
4 | -23.79 | 0.85 | 23.79 | -0.85 | 33.31 | 0.05 | 0.00 | 33 | 33 | 0
5 | -23.74 | 0.85 | 23.74 | -0.85 | 33.24 | 0.06 | 0.00 | 33 | 33 | 0
6 | -23.59 | 0.85 | 23.59 | -0.85 | 33.02 | 0.07 | 0.00 | 33 | 33 | 0
7 | -23.52 | 0.84 | 23.52 | -0.84 | 32.93 | 0.08 | 0.00 | 33 | 33 | 0
8 | -23.45 | 0.85 | 23.45 | -0.85 | 32.83 | 0.08 | 0.00 | 32 | 32 | 0
9 | -23.38 | 0.87 | 23.38 | -0.87 | 32.73 | 0.09 | 0.00 | 32 | 32 | 0
10 | -23.42 | 0.89 | 23.42 | -0.89 | 32.79 | 0.10 | 0.00 | 32 | 32 | 0
11 | -23.47 | 0.89 | 23.47 | -0.89 | 32.85 | 0.11 | 0.00 | 32 | 32 | 0
12 | -23.58 | 0.87 | 23.58 | -0.87 | 33.01 | 0.12 | 0.00 | 33 | 33 | 0
13 | -23.61 | 0.87 | 23.61 | -0.87 | 33.05 | 0.13 | 0.00 | 33 | 33 | 0
14 | -23.61 | 0.87 | 23.61 | -0.87 | 33.05 | 0.14 | 0.00 | 33 | 33 | 0
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

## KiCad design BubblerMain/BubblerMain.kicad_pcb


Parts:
C13: 0.1uF; C_1206_3216Metric_Pad1.33x1.80mm_HandSolder
C19: 1000uF; CP_Elec_10x10
J2, J3, J4, J5: Conn_01x03_Pin; JST_XH_B3B-XH-AM_1x03_P2.50mm_Vertical
R9, R10, R11, R12: 330; R_1206_3216Metric_Pad1.30x1.75mm_HandSolder
U1: 74AHCT125; SOIC-14_3.9x8.7mm_P1.27mm; LCSC C2675672

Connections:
+5V: C13.1, C19.1, J2.3, J3.3, J4.3, J5.3, U1.14 (VCC); also elsewhere on the board
GND1: C13.2, C19.2, J2.1, J3.1, J4.1, J5.1, U1.1, U1.4, U1.7 (GND), U1.10, U1.13; also elsewhere on the board
LED1 Signal: U1.2; also elsewhere on the board
LED2 Signal: U1.5; also elsewhere on the board
LED3 Signal: U1.9; also elsewhere on the board
LED4 Signal: U1.12; also elsewhere on the board
unnamed: J2.2, R9.1
unnamed: J3.2, R10.1
unnamed: J4.2, R11.1
unnamed: J5.2, R12.1
unnamed: R9.2, U1.3
unnamed: R10.2, U1.6
unnamed: R11.2, U1.8
unnamed: R12.2, U1.11


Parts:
5V2: TestPoint; TestPoint_Pad_2.0x2.0mm
C1: 220uf; CP_Elec_10x10
C2, C3: 10uf; C_1206_3216Metric_Pad1.33x1.80mm_HandSolder
C4: 0.1uF; C_1210_3225Metric_Pad1.33x2.70mm_HandSolder
C5, C6: 22uF; C_1210_3225Metric_Pad1.33x2.70mm_HandSolder
C7: 0.1uF; C_1206_3216Metric_Pad1.33x1.80mm_HandSolder
D1: SMAJ13A; D_SMA
F1: Polyfuse; Fuse_1812_4532Metric
GND1: TestPoint; TestPoint_Pad_2.0x2.0mm
J1: Conn_01x04_Pin; JST_XH_B2B-XH-AM_1x02_P2.50mm_Vertical
L1: 3.3uH; IND_SPM6530T-3R3M; PARTREV N/A; LCSC C76856
Q1: DMP3013SFV; Diodes_PowerDI3333-8; LCSC C264098
R1, R2: 100k; R_1206_3216Metric_Pad1.30x1.75mm_HandSolder
R5: 54.9k; R_1206_3216Metric_Pad1.30x1.75mm_HandSolder
R6: 10k; R_1206_3216Metric_Pad1.30x1.75mm_HandSolder
U9: TPS565201DDCR; SOT95P280X110-6N; LCSC C327676

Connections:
+5V: 5V2.1, C5.1, C6.1, L1.2, R5.1; also elsewhere on the board
/Power Block/BAT+: F1.2, J1.1
/Power Block/Fuse-Pol: F1.1, Q1.5 (D)
GND1: C1.2, C2.2, C3.2, C5.2, C6.2, C7.2, D1.1 (A1), GND1.1, J1.2, R1.2, R6.2, U9.1 (GND); also elsewhere on the board
Motor Power: C1.1, C2.1, C3.1, C7.1, D1.2 (A2), Q1.1 (S), Q1.2 (S), Q1.3 (S), R2.1, U9.3 (VIN); also elsewhere on the board
unnamed: Q1.4 (G), R1.1
unnamed: R2.2, U9.5 (EN)
unnamed: C4.1, L1.1, U9.2 (SW)
unnamed: C4.2, U9.6 (VBST)
unnamed: R5.2, R6.1, U9.4 (VFB)

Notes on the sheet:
Output Filter
Input Filter
Spike Protection
Reverse Polarity Protection


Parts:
3.3V1, 5V1: LED; LED_1206_3216Metric_Pad1.42x1.75mm_HandSolder
3v3: TestPoint; TestPoint_Pad_2.0x2.0mm
C8, C21: 1uF; C_1206_3216Metric_Pad1.33x1.80mm_HandSolder
C9, C22: 22uF; C_1210_3225Metric_Pad1.33x2.70mm_HandSolder
C20: 0.1uF; C_1206_3216Metric_Pad1.33x1.80mm_HandSolder
D2, D3: SS14; D_SMA
FB1: 600; L_1206_3216Metric
J8: USB_C_Receptacle; USB_C_Receptacle_HCTL_HC-TYPE-C-16P-01A
J9: Conn_01x08_Pin; PinHeader_1x08_P2.54mm_Vertical
J12: Conn_01x08_Pin; PinHeader_1x04_P2.54mm_Vertical
MOTOR1: LED; LED_1206_3216Metric_Pad1.42x1.75mm_HandSolder
R16, R17: 5.1k; R_1206_3216Metric_Pad1.30x1.75mm_HandSolder
R18, R19: 10k; R_1206_3216Metric_Pad1.30x1.75mm_HandSolder
R20, R22: 1.5k; R_1206_3216Metric_Pad1.30x1.75mm_HandSolder
R21, R23, R26: 680; R_1206_3216Metric_Pad1.30x1.75mm_HandSolder
SW1, SW2: SW_Push; SW_SPST_PTS645Sx43SMTR92
SW3: LED; LED_1206_3216Metric_Pad1.42x1.75mm_HandSolder
U4: ESP32-S3-WROOM-1; ESP32-S3-WROOM-2; LCSC C2913198
U5: AP2112K-3.3; SOT-23-5; LCSC C23380830
U6: USBLC6-2SC6; SOT-23-6; LCSC C2827654
USB1: LED; LED_1206_3216Metric_Pad1.42x1.75mm_HandSolder

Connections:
+3V3: 3v3.1, C20.1, C22.1, J12.3, R18.1, R19.1, R21.1, U4.2 (3V3), U5.5 (VOUT); also elsewhere on the board
+5V: FB1.1, J12.4; also elsewhere on the board
/ESP32/A6: J8.A6 (D+), J8.B6 (D+), U6.4 (I/O2)
/ESP32/A7: J8.A7 (D-), J8.B7 (D-), U6.6 (I/O1)
/ESP32/GPIO8: J9.1, U4.12 (IO8)
/ESP32/GPIO9: J9.2, U4.17 (IO9)
/ESP32/GPIO10: J9.3, U4.18 (IO10)
/ESP32/GPIO11: J9.4, U4.19 (IO11)
/ESP32/GPIO12: J9.5, U4.20 (IO12)
/ESP32/GPIO13: J9.6, U4.21 (IO13)
/ESP32/GPIO14: J9.7, U4.22 (IO14)
/ESP32/GPIO21: J9.8, U4.23 (IO21)
/ESP32/SW_LED: R23.1, U4.25 (IO48)
/ESP32/VBUS: D2.2 (A), J8.A4 (VBUS), J8.A9 (VBUS), J8.B4 (VBUS), J8.B9 (VBUS), R22.1, U6.5 (VBUS)
GND1: 3.3V1.1 (K), 5V1.1 (K), C8.2, C9.2, C20.2, C21.2, C22.2, J8.A1 (GND), J8.A12 (GND), J8.B1 (GND), J8.B12 (GND), J12.1, MOTOR1.1 (K), R16.2, R17.2, SW1.1, SW2.2, SW3.1 (K), U4.1 (GND), U4.40 (GND), U4.41 (GND), U5.2 (GND), U6.2 (GND), USB1.1 (K); also elsewhere on the board
I2S_SCK: U4.9 (IO16); also elsewhere on the board
I2S_SD: U4.11 (IO18); also elsewhere on the board
I2S_WS: U4.10 (IO17); also elsewhere on the board
LED1 Signal: U4.4 (IO4); also elsewhere on the board
LED2 Signal: U4.5 (IO5); also elsewhere on the board
LED3 Signal: U4.6 (IO6); also elsewhere on the board
LED4 Signal: U4.7 (IO7); also elsewhere on the board
Motor Power: J12.2; also elsewhere on the board
Motor Signal: R26.1, U4.8 (IO15); also elsewhere on the board
unnamed 26: 3.3V1.2 (A), R21.2; also elsewhere on the board
unnamed 27: 5V1.2 (A), R20.2; also elsewhere on the board
unnamed: C8.1, C9.1, D2.1 (K), D3.1 (K), R20.1, U5.1 (VIN), U5.3 (EN)
unnamed: D3.2 (A), FB1.2
unnamed: MOTOR1.2 (A), R26.2
unnamed 45: R23.2, SW3.2 (A); also elsewhere on the board
unnamed: C21.1, R18.2, SW1.2, U4.3 (EN)
unnamed: R19.2, SW2.1, U4.27 (IO0)
unnamed: U4.14 (USB_D+/IO20), U6.3 (I/O2)
unnamed: U4.13 (USB_D-/IO19), U6.1 (I/O1)
unnamed 57: R22.2, USB1.2 (A); also elsewhere on the board
RS485_DE: U4.35 (MTMS/IO42); also elsewhere on the board
RS485_RX: U4.38 (IO2); also elsewhere on the board
RS485_TX: U4.39 (IO1); also elsewhere on the board

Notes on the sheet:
Expansion Header for future use


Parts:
C8, C21: 1uF
C20: 0.1uF
C22: 22uF
D2: SS14
D4, D5, D6, D7: LED
J8: USB_C_Receptacle
R16, R17: 5.1k
R18, R19: 10k
R20, R22: 1.5k
R21, R23: 680
SW1, SW2: SW_Push
U4: ESP32-S3-WROOM-1; ESP32-S3-WROOM-2
U5: AP2112K-3.3; SOT-23-5
U6: USBLC6-2SC6; SOT-23-6

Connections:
+3V3: C20.1, C22.1, R18.1, R19.1, R21.1, U4.2 (3V3), U5.5 (VOUT); also elsewhere on the board
/ESP32/A6: J8.A6 (D+), J8.B6 (D+), U6.4 (I/O2)
/ESP32/A7: J8.A7 (D-), J8.B7 (D-), U6.6 (I/O1)
/ESP32/GPIO8: U4.12 (IO8); also elsewhere on the board
/ESP32/GPIO9: U4.17 (IO9); also elsewhere on the board
/ESP32/GPIO10: U4.18 (IO10); also elsewhere on the board
/ESP32/GPIO11: U4.19 (IO11); also elsewhere on the board
/ESP32/GPIO12: U4.20 (IO12); also elsewhere on the board
/ESP32/GPIO13: U4.21 (IO13); also elsewhere on the board
/ESP32/GPIO14: U4.22 (IO14); also elsewhere on the board
/ESP32/GPIO21: U4.23 (IO21); also elsewhere on the board
/ESP32/SW_LED: R23.1, U4.25 (IO48)
/ESP32/VBUS: D2.2 (A), J8.A4 (VBUS), J8.A9 (VBUS), J8.B4 (VBUS), J8.B9 (VBUS), R22.1, U6.5 (VBUS)
GND1: C8.2, C20.2, C21.2, C22.2, D4.1 (K), D5.1 (K), D6.1 (K), D7.1 (K), J8.A1 (GND), J8.A12 (GND), J8.B1 (GND), J8.B12 (GND), R16.2, R17.2, SW1.1, SW2.2, U4.1 (GND), U4.40 (GND), U4.41 (GND), U5.2 (GND), U6.2 (GND); also elsewhere on the board
I2S_SCK: U4.9 (IO16); also elsewhere on the board
I2S_SD: U4.11 (IO18); also elsewhere on the board
I2S_WS: U4.10 (IO17); also elsewhere on the board
LED1 Signal: U4.4 (IO4); also elsewhere on the board
LED2 Signal: U4.5 (IO5); also elsewhere on the board
LED3 Signal: U4.6 (IO6); also elsewhere on the board
LED4 Signal: U4.7 (IO7); also elsewhere on the board
Motor Signal: U4.8 (IO15); also elsewhere on the board
unnamed 26: D5.2 (A), R21.2; also elsewhere on the board
unnamed 27: D4.2 (A), R20.2; also elsewhere on the board
unnamed 28: C8.1, D2.1 (K), R20.1, U5.1 (VIN), U5.3 (EN); also elsewhere on the board
unnamed 45: D7.2 (A), R23.2; also elsewhere on the board
unnamed: C21.1, R18.2, SW1.2, U4.3 (EN)
unnamed: R19.2, SW2.1, U4.27 (IO0)
unnamed: U4.14 (USB_D+/IO20), U6.3 (I/O2)
unnamed: U4.13 (USB_D-/IO19), U6.1 (I/O1)
unnamed 57: D6.2 (A), R22.2; also elsewhere on the board
RS485_DE: U4.35 (MTMS/IO42); also elsewhere on the board
RS485_RX: U4.38 (IO2); also elsewhere on the board
RS485_TX: U4.39 (IO1); also elsewhere on the board


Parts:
C14, C15: 10uF 25v; C_1206_3216Metric_Pad1.33x1.80mm_HandSolder
C16: 0.1uF; C_1206_3216Metric_Pad1.33x1.80mm_HandSolder
C17, C18: 22uF; C_1210_3225Metric_Pad1.33x2.70mm_HandSolder
J6, J7: Conn_01x02_Pin; JST_XH_B2B-XH-AM_1x02_P2.50mm_Vertical
L2: 3.3uH; IND_SPM6530T-3R3M; PARTREV N/A; LCSC C76856
R13: 35.7k; R_1206_3216Metric_Pad1.30x1.75mm_HandSolder
R14: 10k; R_1206_3216Metric_Pad1.30x1.75mm_HandSolder
R15: 100k; R_1206_3216Metric_Pad1.30x1.75mm_HandSolder
U3: TPS563201DDCR; TSOT-23-6_HandSoldering; PARTREV December 2015; LCSC C116592

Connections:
GND1: C14.2, C15.2, C17.2, C18.2, J6.1, J7.1, R14.2, R15.2, U3.1 (GND); also elsewhere on the board
Motor Power: C14.1, C15.1, U3.3 (VIN); also elsewhere on the board
Motor Signal: R15.1, U3.5 (EN); also elsewhere on the board
unnamed: C17.1, C18.1, J6.2, J7.2, L2.2, R13.1
unnamed: C16.1, L2.1, U3.2 (SW)
unnamed: C16.2, U3.6 (VBST)
unnamed: R13.2, R14.1, U3.4 (VFB)


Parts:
C23, C24: 0.1uF; C_1206_3216Metric_Pad1.33x1.80mm_HandSolder
C25: 4.7uF; C_1206_3216Metric_Pad1.33x1.80mm_HandSolder
J10: Conn_01x04_Pin; JST_XH_B2B-XH-AM_1x02_P2.50mm_Vertical
J11: Conn_01x08_Pin; JST_XH_B8B-XH-AM_1x08_P2.50mm_Vertical
R24, R29: 100k; R_1206_3216Metric_Pad1.30x1.75mm_HandSolder
R25: 120; R_1206_3216Metric_Pad1.30x1.75mm_HandSolder
R27, R28: 33; R_1206_3216Metric_Pad1.30x1.75mm_HandSolder
U7: THVD1400D; SOIC-8_3.9x4.9mm_P1.27mm; LCSC C3235232
U8: SM712; SOT23-WIDE; LCSC C502564

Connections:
+3V3: C23.1, C24.1, C25.1, J11.1, U7.8 (VCC); also elsewhere on the board
GND1: C23.2, C24.2, C25.2, J11.2, J11.4, J11.6, J11.8, R24.2, R29.2, U7.5 (GND), U8.3; also elsewhere on the board
I2S_SCK: R27.2; also elsewhere on the board
I2S_SD: J11.7, R29.1; also elsewhere on the board
I2S_WS: R28.2; also elsewhere on the board
unnamed: J10.1, R25.2, U7.7 (B), U8.1
unnamed: J10.2, R25.1, U7.6 (A), U8.2
unnamed: J11.3, R27.1
unnamed: J11.5, R28.1
RS485_DE: R24.1, U7.2 (~RE), U7.3 (DE); also elsewhere on the board
RS485_RX: U7.1 (RO); also elsewhere on the board
RS485_TX: U7.4 (DI); also elsewhere on the board

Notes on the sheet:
RS485 Transceiver
INMP441 Module Header
INMP441 Module will be on an 8-10 inch lead from the PCB Connected with CAT5 twisted pair. Ground/Signal for each twisted pair.

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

Board: 4 copper layers, 72.0 x 66.0 mm, 85 parts (0 on the bottom side), 63 nets.

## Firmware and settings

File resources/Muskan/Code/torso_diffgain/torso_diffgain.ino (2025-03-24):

#include <Wire.h>

int pin1 = 9;
int pin2 = 10;
int frequency = 50;
#define max_signal 26
#define min_signal 13

//variables for mpu6050
float RateRoll, RatePitch, RateYaw;
float AccX, AccY, AccZ;
float AngleRoll, AnglePitch;

//variables for pid
unsigned long timePrev; 
unsigned long elapsedTime;
int i;
float rad_to_deg = 180/3.141592654;

float PIDl, PIDr, pwmLeft, pwmRight, error, previous_error;
float pid_pl=0;
float pid_il=0;
float pid_dl=0;

float pid_pr=0;
float pid_ir=0;
float pid_dr=0;

double kpl=25;//3.55
double kil=0.5;//0.005
double kdl=15;//2.05

double kpr=15;//3.55
double kir=0.8;//0.005
double kdr=10;//2.05

int pwm1, pwm2;

double throttle=1100; //initial value of throttle to the motors
float desired_angle = 0; //steady state


void setup() {
  // put your setup code here, to run once:
  pinMode(pin1, OUTPUT);
  pinMode(pin2, OUTPUT);

  analogWriteFrequency(pin1, frequency);
  analogWriteFrequency(pin2, frequency);

  Wire.setClock (400000);  //specification on mcu6050
  Wire.begin();
  delay(250);

  setup_mpu_6050_registers();

  Serial.begin(9600);
  Serial.println("Program begin...");
  delay(1000);
  Serial.println("This program will start the ESC.");

  Serial.print("Now writing maximum output: (");Serial.print(max_signal);Serial.print(" in this case)");Serial.print("\n");
  Serial.println("Turn on power source, then wait 2 seconds and press any key.");
  analogWrite(pin1, max_signal);
  analogWrite(pin2, max_signal);

  // Wait for input
  while (!Serial.available());
  Serial.read();

  // Send min output
  Serial.println("\n");
  Serial.println("\n");
  Serial.print("Sending minimum output: (");Serial.print(min_signal);Serial.print(" us in this case)");Serial.print("\n");
  analogWrite(pin1, min_signal);
  analogWrite(pin2, min_signal);

  Serial.println("The ESC is calibrated");
  Serial.println("----");

  delay(2000);

  //unsigned long time = millis(); //Start counting time in milliseconds

}

void loop() {
  // put your main code here, to run repeatedly:
  unsigned long time = millis();  // actual time read
  //double elapsedTime = (double)((time - timePrev) / 1000);

  read_mpu_6050_data();
  Serial.print(AngleRoll);
  Serial.print(",");

  //PID
  error = desired_angle - AngleRoll;
  /*Next the proportional value of the PID is just a proportional constant
*multiplied by the error*/

pid_pl = kpl*error;
pid_pr = kpr*error;

/*The integral part should only act if we are close to the
desired position but we want to fine tune the error. That's
why I've made a if operation for an error between -2 and 2 degree.
To integrate we just sum the previous integral value with the
error multiplied by  the integral constant. This will integrate (increase)
the value each loop till we reach the 0 point*/
/*if(-3 <error <3)
{
  pid_i = pid_i+(ki*error);  
}*/

pid_il = kil*error*elapsedTime;
pid_ir = kir*error*elapsedTime;

/*The last part is the derivate. The derivate acts upon the speed of the error.
As we know the speed is the amount of error that produced in a certain amount of
time divided by that time. For taht we will use a variable called previous_error.
We substract that value from the actual error and divide all by the elapsed time. 
Finnaly we multiply the result by the derivate constant*/

pid_dl = kdl*((error - previous_error)/elapsedTime);
pid_dr = kdr*((error - previous_error)/elapsedTime);
//pid_d = kd*(error - previous_error);

//Serial.print(pid_pl);
//Serial.print(",");
//Serial.print(pid_il);
//Serial.print(",");
//Serial.print(pid_dl);
//Serial.print(",");

/*The final PID values is the sum of each of this 3 parts*/
PIDl = pid_pl + pid_il + pid_dl;
PIDr = pid_pr + pid_ir + pid_dr;

Serial.print(PIDl);
Serial.print(",");
Serial.print(PIDr);
Serial.print(",");

/*We know taht the min value of PWM signal is 1000us and the max is 2000. So that
tells us that the PID value can/s oscilate more than -1000 and 1000 because when we
have a value of 2000us the maximum value taht we could sybstract is 1000 and when
we have a value of 1000us for the PWM sihnal, the maximum value that we could add is 1000
to reach the maximum 2000us*/
if(PIDl < -1000)
{
  PIDl=-1000;
}
if(PIDl > 1000)
{
  PIDl=1000;
}

if(PIDr < -1000)
{
  PIDr=-1000;
}
if(PIDr > 1000)
{
  PIDr=1000;
}

/*Finnaly we calculate the PWM width. We sum the desired throttle and the PID value*/
pwmLeft = throttle + PIDl;
pwmRight = throttle - PIDr;


/*Once again we map the PWM values to be sure that we won't pass the min
and max values. Yes, we've already maped the PID values. But for example, for 
throttle value of 1300, if we sum the max PID value we would have 2300us and
that will mess up the ESC.*/
//Right
if(pwmRight < 1000)
{
  pwmRight= 1000;
}
if(pwmRight > 2000)
{
  pwmRight=2000;
}
//Left
if(pwmLeft < 1000)
{
  pwmLeft= 1000;
}
if(pwmLeft > 2000)
{
  pwmLeft=2000;
}

pwm1 = map(pwmRight, 1000, 2000, 13, 26);
pwm2 = map(pwmLeft, 1000, 2000, 13, 26);
/*Finnaly using the servo function we create the PWM pulses with the calculated
width for each pulse*/

analogWrite(pin1, pwm1);
analogWrite(pin2, pwm2);

//Serial.print("pwm1 = ");
Serial.print(pwm1);
Serial.print(",");
//Serial.print("pwm2 = ");
Serial.println(pwm2);

previous_error = error; //Remember to store the previous error.
elapsedTime = time - timePrev;
timePrev = time;

//Serial.print(time);
//Serial.print(",");
//Serial.print(timePrev);
//Serial.print(",");
//Serial.println(elapsedTime);

}

void setup_mpu_6050_registers(){

  //Activate the MPU-6050
  Wire.beginTransmission(0x68);
  Wire.write (0x6B);  //start gyro in power mode using power management register
  Wire.write (0x00);  //set to zero for device to start and continue in power mode
  Wire.endTransmission();
  
  //Start communicating with the MPU-6050
  Wire.beginTransmission(0x68); 
  //switch to low pass filter                                       
  Wire.write(0x1A);  
  //set the cutoff freq of the gyro to 10Hz                                                  
  Wire.write(0x05);
  //End the transmission                                                    
  Wire.endTransmission(); 
                                              
  //Configure the accelerometer (+/-8g)
  
  //Start communicating with the MPU-6050
  Wire.beginTransmission(0x68); 
  //Send the requested starting register                                       
  Wire.write(0x1C);   
  //Configure the accelerometer output                                                 
  Wire.write(0x10); 
  //set the full scale range of 8g = LSB sensitivity = 4096LSB/g                                                   
  Wire.endTransmission(); 
                                              
  //Configure the gyro (500dps full scale)
  
  //Start communicating with the MPU-6050
  Wire.beginTransmission(0x68);
  //Send the requested starting register                                        
  Wire.write(0x1B);
  //Set the requested starting register                                                    
  Wire.write(0x8); 
  //End the transmission                                                  
  Wire.endTransmission(); 
                                              
}

void read_mpu_6050_data(){ 

  //Read the raw gyro and accelerometer data

  //Start communicating with the MPU-6050                                          
  Wire.beginTransmission(0x68);  
  //Send the requested starting register                                      
  Wire.write(0x3B);
  //End the transmission                                                    
  Wire.endTransmission(); 
                               
  Wire.requestFrom(0x68,6);  //pull info from six registers   

  int16_t AccXLSB=Wire.read()<<8 | Wire.read(); //measurement of the acc is set to 16-bit and read measurements around x-axis
  int16_t AccYLSB=Wire.read()<<8 | Wire.read(); //measurement of the acc is set to 16-bit and read measurements around y-axis
  int16_t AccZLSB=Wire.read()<<8 | Wire.read(); //measurement of the acc is set to 16-bit and read measurements around z-axis

  Wire.beginTransmission(0x68);
  Wire.write(0x43);  //use the first register to get measurements of gyro
  Wire.endTransmission();
  
  Wire.requestFrom(0x68,6);  //pull info from six registers 67-72
  
  int16_t GyroX=Wire.read()<<8 | Wire.read(); //measurement of the gyro is set to 16-bit and read measurements around x-axis
  int16_t GyroY=Wire.read()<<8 | Wire.read(); //measurement of the gyro is set to 16-bit and read measurements around y-axis
  int16_t GyroZ=Wire.read()<<8 | Wire.read(); //measurement of the gyro is set to 16-bit and read measurements around z-axis

  RateRoll=(float)GyroX/65.5; //Convert measurements to deg/sec
  RatePitch=(float)GyroY/65.5;
  RateYaw=(float)GyroZ/65.5;

  AccX = (float)AccXLSB/4096; //Convert measurements to physical values
  AccY = (float)AccYLSB/4096; //Convert measurements to physical values
  AccZ = (float)AccZLSB/4096; //Convert measurements to physical values

  AngleRoll = atan(AccY/sqrt(AccX*AccX+AccZ*AccZ))*180/3.142+0.75;
  AnglePitch = atan(AccX/sqrt(AccY*AccY+AccZ*AccZ))*180/3.142;

}

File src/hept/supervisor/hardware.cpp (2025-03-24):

#include "hardware.h"

/// White Line Sensor Values ///////////
void wls_init() {
  pinMode(Clock, OUTPUT);
  pinMode(Address, OUTPUT);
  pinMode(DataOut, INPUT);
  pinMode(CS, OUTPUT);
}

void AnalogRead(int *sensorValues) {
  char i,j;
  unsigned int channel = 0;
  unsigned int values[] = {0,0,0,0,0,0,0,0};

  for(j = 0;j < 5 + 1;j++)
  {
    digitalWrite(CS,LOW);
    for(i = 0;i < 8;i++)
    {
      if(i<4)
      {
        //0 to 4 clock transfer channel address
        if((j >> (3 - i) & 0x01))
          digitalWrite(Address,HIGH);
        else
          digitalWrite(Address,LOW);
      }
      else
      {
        digitalWrite(Address,LOW);
      }
      

      //0 to 10 clock receives the previous conversion result
      values[j] <<= 1;
      if(digitalRead(DataOut)) 
      values[j] |= 0x01;
      digitalWrite(Clock,HIGH);
      digitalWrite(Clock,LOW);
    }
    //sent 11 to 16 clock 
    for(i = 0;i < 4;i++)
    {
      values[j] <<= 1;
      if(digitalRead(DataOut)) 
      values[j] |= 0x01;
      digitalWrite(Clock,HIGH);
      digitalWrite(Clock,LOW);
    }
    digitalWrite(CS,HIGH);
  }
  for(i = 0;i < 5 + 1;i++)
  {
    values[i] = values[i] >> 2;
  }

  for(i = 0;i < 5;i++)
  {
    sensorValues[i] = values[i+1];
  }
}

/// Motion related ///////////



void motion(bool LF, bool LB, bool RF, bool RB) {
  digitalWrite(INLF, LF);
  digitalWrite(INLB, LB);
  digitalWrite(INRF, RF);
  digitalWrite(INRB, RB);
}

void forward() {
    motion(HIGH, LOW, HIGH, LOW);
}

void backward() {
    motion(LOW, HIGH, LOW, HIGH);
}

void right() {
    motion(HIGH, LOW, LOW, HIGH);
}

void left() {
    motion(LOW, HIGH, HIGH, LOW);
}

void forward_right() {
    motion(HIGH, LOW, LOW, LOW);
}

void forward_left() {
    motion(LOW, LOW, HIGH, LOW);
}

void back_right() {
    motion(LOW, LOW, LOW, HIGH);
}

void back_left() {
    motion(LOW, HIGH, LOW, LOW);
}

void stop() {
    motion(LOW, LOW, LOW, LOW);
}

void SetSpeed(char LSpeed,char RSpeed) {
  analogWrite(ENR, RSpeed);  
  analogWrite(ENL, LSpeed);  
}
void motion_init() {
  pinMode(ENL, OUTPUT);
  pinMode(ENR, OUTPUT);
  pinMode(INLF, OUTPUT);
  pinMode(INLB, OUTPUT);
  pinMode(INRF, OUTPUT);
  pinMode(INRB, OUTPUT);
  // SetSpeed(100, 100);
}

///  Port expander related //////////

void port_expander_init() {
    Wire.begin();
}

void PCF8574Write(byte data)
{
  Wire.beginTransmission(Addr);
  Wire.write(data);
  Wire.endTransmission(); 
}

byte PCF8574Read()
{
  int data = -1;
  Wire.requestFrom(Addr, 1);
  if(Wire.available()) {
    data = Wire.read();
  }
  return data;
}


void beep_on() {
     PCF8574Write(0xDF & PCF8574Read());
}

void beep_off() {
     PCF8574Write(0x20 | PCF8574Read());
}

char joystick_read() {
  char return_val = 'n';
    PCF8574Write(0x1F | PCF8574Read());
  byte value = PCF8574Read() | 0xE0;
  if(value != 0xFF)
  {
    switch(value)
    { 
      case 0xFE:  // up
        return_val = 'u';
        break; 
      case 0xFD:  // right
        return_val = 'r';
        break;
      case 0xFB:  // left
        return_val = 'l';
        break; 
      case 0xF7:  // down
        return_val = 'd';
        break;
      case 0xEF:   // center
        return_val = 'c';
        break;
    }
    while(value != 0xFF)
    {
      PCF8574Write(0x1F | PCF8574Read());
      value = PCF8574Read() | 0xE0;
      delay(10);
    }
  }
  return (return_val);
}

char ir_read() {
  PCF8574Write(0xC0 | PCF8574Read());   //set Pin High
  byte value = PCF8574Read() | 0x3F;         //read Pin
  if(value != 0xFF)
  {
    if (value == 63)
    return ('b');
    if (value == 127)
    return ('l');
    else
    return ('r');
  }
  return('n');
}

///////  Ultrasonic related ///
void ultrasonic_init(){
  pinMode(ECHO, INPUT);    // Define the ultrasonic echo input pin
  pinMode(TRIG, OUTPUT);   // Define the ultrasonic trigger input pin 
}


int Distance_test()         // Measure the distance 
{
  digitalWrite(TRIG, LOW);   // set trig pin low 2μs
  delayMicroseconds(2);
  digitalWrite(TRIG, HIGH);  // set trig pin 10μs , at last 10us 
  delayMicroseconds(10);
  digitalWrite(TRIG, LOW);    // set trig pin low
  float Fdistance = pulseIn(ECHO, HIGH);  // Read echo pin high level time(us)
  Fdistance= Fdistance/58;       //Y m=（X s*344）/2
  // X s=（ 2*Y m）/344 ==》X s=0.0058*Y m ==》cm = us /58       
  return (int)Fdistance;
}  

void init_devices(){
  ultrasonic_init();
  port_expander_init();
  motion_init();
  wls_init();
}

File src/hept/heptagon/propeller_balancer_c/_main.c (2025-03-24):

/* --- Generated the 24/3/2025 at 19:45 --- */
/* --- heptagon compiler, version 1.05.00 (compiled sat. jan. 18 10:20:49 CET 2025) --- */
/* --- Command line: /usr/local/bin/heptc -target c -s main -hepts propeller_balancer.ept --- */

#include <stdio.h>
#include <string.h>
#include <stdlib.h>
#include "_main.h"

Propeller_balancer__main_mem mem;
int main(int argc, char** argv) {
  int step_c;
  int step_max;
  float raw_a;
  Propeller_balancer__main_out _res;
  step_c = 0;
  step_max = 0;
  if ((argc==2)) {
    step_max = atoi(argv[1]);
  };
  Propeller_balancer__main_reset(&mem);
  while ((!(step_max)||(step_c<step_max))) {
    step_c = (step_c+1);
    
    if ((scanf("%f", &raw_a)==EOF)) {
      return 0;
    };;
    Propeller_balancer__main_step(raw_a, &_res, &mem);
    printf("%d\n", _res.pwmL);
    printf("%d\n", _res.pwmR);
    fflush(stdout);
  };
  return 0;
}

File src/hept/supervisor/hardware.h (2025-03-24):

#include "Arduino.h"
#include <Wire.h>


#define Clock     13
#define Address   12
#define DataOut   11
#define CS        10

#define NUM_SENSORS 5

#define DefaultSpeed 255
#define ENL 6
#define ENR 5

#define INLF A0
#define INLB A1
#define INRF A3
#define INRB A2

#define Addr  0x20

#define ECHO   2
#define TRIG   3

#define PIN 7

void sensor_init(void);
void AnalogRead(int *);

void motion_init(void);
void forward(void);
void backward();
void right();
void left();
void forward_right();
void forward_left();
void back_right();
void back_left();
void stop();
void SetSpeed(char ,char );

void beep_on();
void beep_off();

char joystick_read();
char ir_read();

void ultrasonic_init();
int Distance_test();

void init_devices();

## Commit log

2025-03-24 added resources
    [2020 alu section_100.SLDPRT, 2020 alu section_vertical.SLDPRT, 30A ESC SimonK Firmware.SLDPRT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]
2025-04-02 Update README.md with teensy resources
2025-04-05 added datasheet for IMU
2025-04-05 Added imu device files
2025-04-06 Added KiCAD circuit and updated README with IMU and connecitons details
    [muc_imu_pdb_ckt.kicad_pcb, muc_imu_pdb_ckt.kicad_sch]
2025-04-07 added code for motor and propeller_balance with sample ino files
2025-04-07 developed project structure and verified imu functionality
2025-04-07 tested motors and integrated callibration
2025-04-15 motor testing
    [thrust_test.xlsx]
2025-04-15 motor testing worklog
2025-04-24 added worklog and verified simultaneous motor callibration
2025-04-24 debugged src code
    [Part1.SLDPRT, mounts.DXF]
2025-05-06 fixed esc and tuned pid
    [pid_test1.csv]
2025-05-07 tuned pid
    [final_test.csv]
2025-05-07 added images and report
    [final_test.csv, pid_test1.csv, test_data.csv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]
2025-05-26 added CAD files
    [11x4.7_9mm.SLDPRT, 11x4.7_9mm.STEP, 2020T.SLDPRT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]
2025-06-02 added kicad lib and sim code
    [Part1.SLDPRT, mounts.DXF]
